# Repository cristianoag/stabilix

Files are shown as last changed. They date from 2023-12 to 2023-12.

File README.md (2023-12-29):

# Stabilix

Stabilix is a spin-off of the self-balancing robot project called B-ROBOT EVO created by JJ Robotics. 

It is a platform for experiments with different sensors and algorithms. The robot is able to balance itself on two wheels and move around avoiding obstacles. The robot is based on ESP32 and it is remotely controlled using a smartphone via Bluetooth.

## Hardware

The robot is based on ESP32 microcontroller and it is remotely controlled using a smartphone via Bluetooth. The robot is equipped with the following hardware components:

* 1 x MPU6050 - 6-axis accelerometer and gyroscope
* 2 x NEMA17 stepper motors
* 2 x A4988 stepper motor drivers
* 1 x ESP32 microcontroller

The robot is powered by a 7.4V LIPO battery pack. The battery is connected to a voltage regulator that converts the voltage to 5V. The 5V is used to power the ESP32 microcontroller and the stepper motor drivers. The stepper motors are powered directly from the battery.

## Assembly

The robot is assembled using 3D printed parts. The 3D models are available in the `3D_models` folder. The robot is assembled using the following parts:

### Bill of materials

| Part name | Quantity | Link |
| --- | --- | --- |
| 3D printed parts | 1 | [Thingiverse](https://www.thingiverse.com/thing:2786294) |

## Software

The robot is programmed in C++ using Arduino IDE. The code is based on the B-ROBOT EVO project created by JJ Robotics. 

## Installation

1. Download and install Arduino IDE from [here](https://www.arduino.cc/en/software)
2. Download and install ESP32 board support for Arduino IDE from [here]()
3. Download the code from this repository and open it in Arduino IDE
4. Connect the robot to your computer using a USB cable
5. Select the correct board and port in Arduino IDE
6. Upload the code to the robot

## Usage

1. Download and install the B-ROBOT EVO app from [here](https://play.google.com/store/apps/details?id=com.jjrobots.brobotevoremotecontrol&hl=en&gl=US)

2. Turn on the robot and connect to it using the app

3. Use the app to control the robot

## Contributing

Pull requests are welcome. For major changes, please open an issue first to discuss what you would like to change.

## License

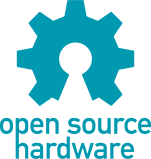
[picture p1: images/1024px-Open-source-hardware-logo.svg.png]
open hardware


This work is licensed under the CERN OHL-S v2. You may redistribute and modify this project and its documentation under the terms of the CERN-OHL-S v2.

This project is distributed WITHOUT ANY EXPRESS OR IMPLIED WARRANTY, INCLUDING OF MERCHANTABILITY, SATISFACTORY QUALITY AND FITNESS FOR A PARTICULAR PURPOSE. Please see the CERN-OHL-S v2 for applicable conditions.

You should have received a copy of the CERN-OHL-S along with this project. If not, see <https://ohwr.org/project/cernohl/wikis/Documents/CERN-OHL-version-2>.

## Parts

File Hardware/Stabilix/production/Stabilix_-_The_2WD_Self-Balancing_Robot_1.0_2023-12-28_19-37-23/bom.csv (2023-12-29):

Designator | Footprint | Quantity | Value | LCSC Part #
BZ1 | Buzzer_12x9.5RM7.6 | 1 | Buzzer
C1, C3 | CP_Radial_D6.3mm_P2.50mm | 2 | 220uF/16V
C2 | CP_Radial_D5.0mm_P2.50mm | 1 | 100uF/16V
D1, D2 | LED_D3.0mm | 2 | LED
J1 | PinHeader_1x04_P2.54mm_Vertical | 1 | NEMA17-M1
J2 | PinHeader_1x04_P2.54mm_Vertical | 1 | NEMA17-M2
J3 | TerminalBlock_bornier-2_P5.08mm | 1 | KF35-2P Battery
J4 | PinHeader_1x02_P2.54mm_Vertical | 1 | Power Switch
J5 | PinHeader_1x03_P2.54mm_Vertical | 1 | Servo
J6 | PinHeader_2x04_P2.54mm_Vertical | 1 | Expansion
R1 | R_Axial_DIN0207_L6.3mm_D2.5mm_P10.16mm_Horizontal | 1 | 1K
U1, U2 | SOT-223-3_TabPin2 | 2 | AMS1117-5.0
U3, U4 | MODULE_A4988_STEPPER_MOTOR_DRIVER_CARRIER | 2 | A4988_STEPPER_MOTOR_DRIVER_CARRIER
U5 | module_mpu6050 | 1 | module_mpu6050
U6 | MODULE_ESP32_DEVKIT_V1 | 1 | ESP32-DEVKIT-V1

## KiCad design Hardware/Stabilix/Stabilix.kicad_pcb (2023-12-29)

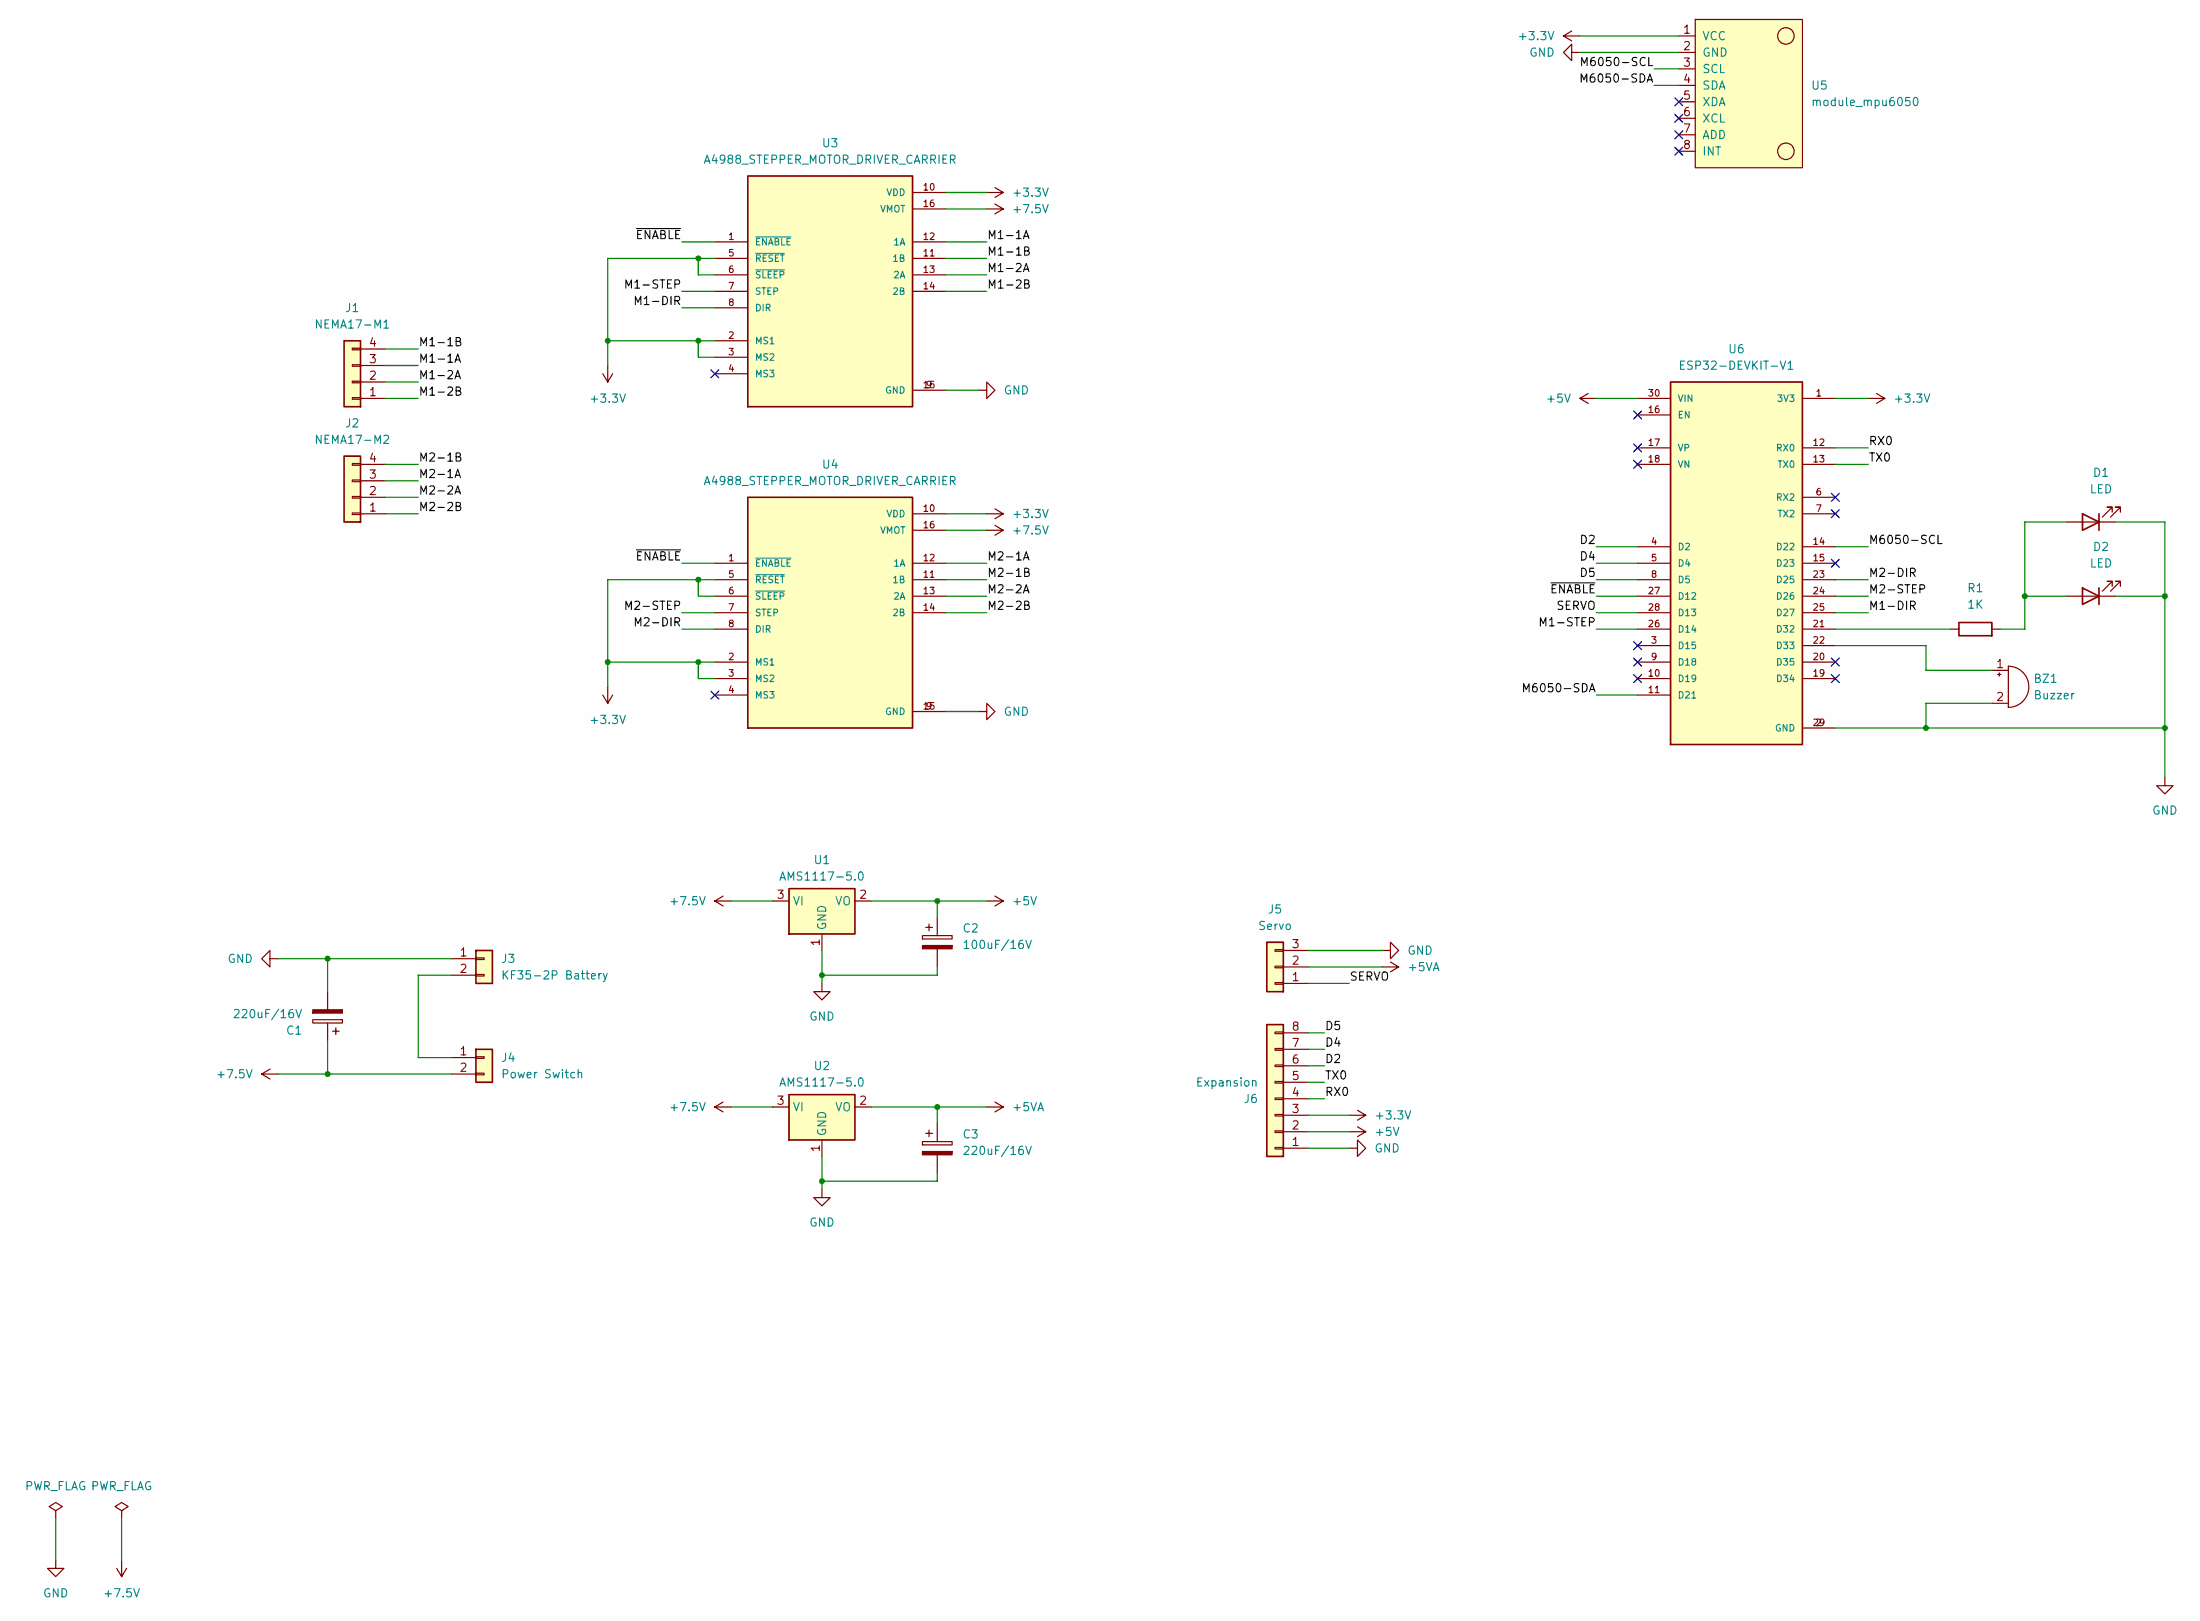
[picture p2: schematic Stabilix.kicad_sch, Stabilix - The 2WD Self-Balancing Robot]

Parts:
BZ1: Buzzer; Buzzer_12x9.5RM7.6
C1, C3: 220uF/16V; CP_Radial_D6.3mm_P2.50mm
C2: 100uF/16V; CP_Radial_D5.0mm_P2.50mm
D1, D2: LED; LED_D3.0mm
J1: NEMA17-M1; PinHeader_1x04_P2.54mm_Vertical
J2: NEMA17-M2; PinHeader_1x04_P2.54mm_Vertical
J3: KF35-2P Battery; TerminalBlock_bornier-2_P5.08mm
J4: Power Switch; PinHeader_1x02_P2.54mm_Vertical
J5: Servo; PinHeader_1x03_P2.54mm_Vertical
J6: Expansion; PinHeader_2x04_P2.54mm_Vertical
R1: 1K; R_Axial_DIN0207_L6.3mm_D2.5mm_P10.16mm_Horizontal
U1, U2: AMS1117-5.0; SOT-223-3_TabPin2
U3, U4: A4988_STEPPER_MOTOR_DRIVER_CARRIER; MODULE_A4988_STEPPER_MOTOR_DRIVER_CARRIER
U5: module_mpu6050
U6: ESP32-DEVKIT-V1; MODULE_ESP32_DEVKIT_V1; PARTREV N/A

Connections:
+3.3V: J6.3, U3.2 (MS1), U3.3 (MS2), U3.5 (~RESET), U3.6 (~SLEEP), U3.10 (VDD), U4.2 (MS1), U4.3 (MS2), U4.5 (~RESET), U4.6 (~SLEEP), U4.10 (VDD), U5.1 (VCC), U6.1 (3V3)
+5V: C2.1, J6.2, U1.2 (VO), U6.30 (VIN)
+5VA: C3.1, J5.2, U2.2 (VO)
+7.5V: C1.1, J4.2, U1.3 (VI), U2.3 (VI), U3.16 (VMOT), U4.16 (VMOT)
/D2: J6.6, U6.4 (D2)
/D4: J6.7, U6.5 (D4)
/D5: J6.8, U6.8 (D5)
/M1-1A: J1.3, U3.12 (1A)
/M1-1B: J1.4, U3.11 (1B)
/M1-2A: J1.2, U3.13 (2A)
/M1-2B: J1.1, U3.14 (2B)
/M1-DIR: U3.8 (DIR), U6.25 (D27)
/M1-STEP: U3.7 (STEP), U6.26 (D14)
/M2-1A: J2.3, U4.12 (1A)
/M2-1B: J2.4, U4.11 (1B)
/M2-2A: J2.2, U4.13 (2A)
/M2-2B: J2.1, U4.14 (2B)
/M2-DIR: U4.8 (DIR), U6.23 (D25)
/M2-STEP: U4.7 (STEP), U6.24 (D26)
/M6050-SCL: U5.3 (SCL), U6.14 (D22)
/M6050-SDA: U5.4 (SDA), U6.11 (D21)
/RX0: J6.4, U6.12 (RX0)
/SERVO: J5.1, U6.28 (D13)
/TX0: J6.5, U6.13 (TX0)
/~ENABLE: U3.1 (~ENABLE), U4.1 (~ENABLE), U6.27 (D12)
GND: BZ1.2 (+), C1.2, C2.2, C3.2, D1.1 (K), D2.1 (K), J3.1, J5.3, J6.1, U1.1 (GND), U2.1 (GND), U3.9 (GND), U3.15 (GND), U4.9 (GND), U4.15 (GND), U5.2 (GND), U6.2 (GND), U6.29 (GND)
unnamed: BZ1.1 (-), U6.22 (D33)
unnamed: D1.2 (A), D2.2 (A), R1.2
unnamed: J3.2, J4.1
unnamed: R1.1, U6.21 (D32)

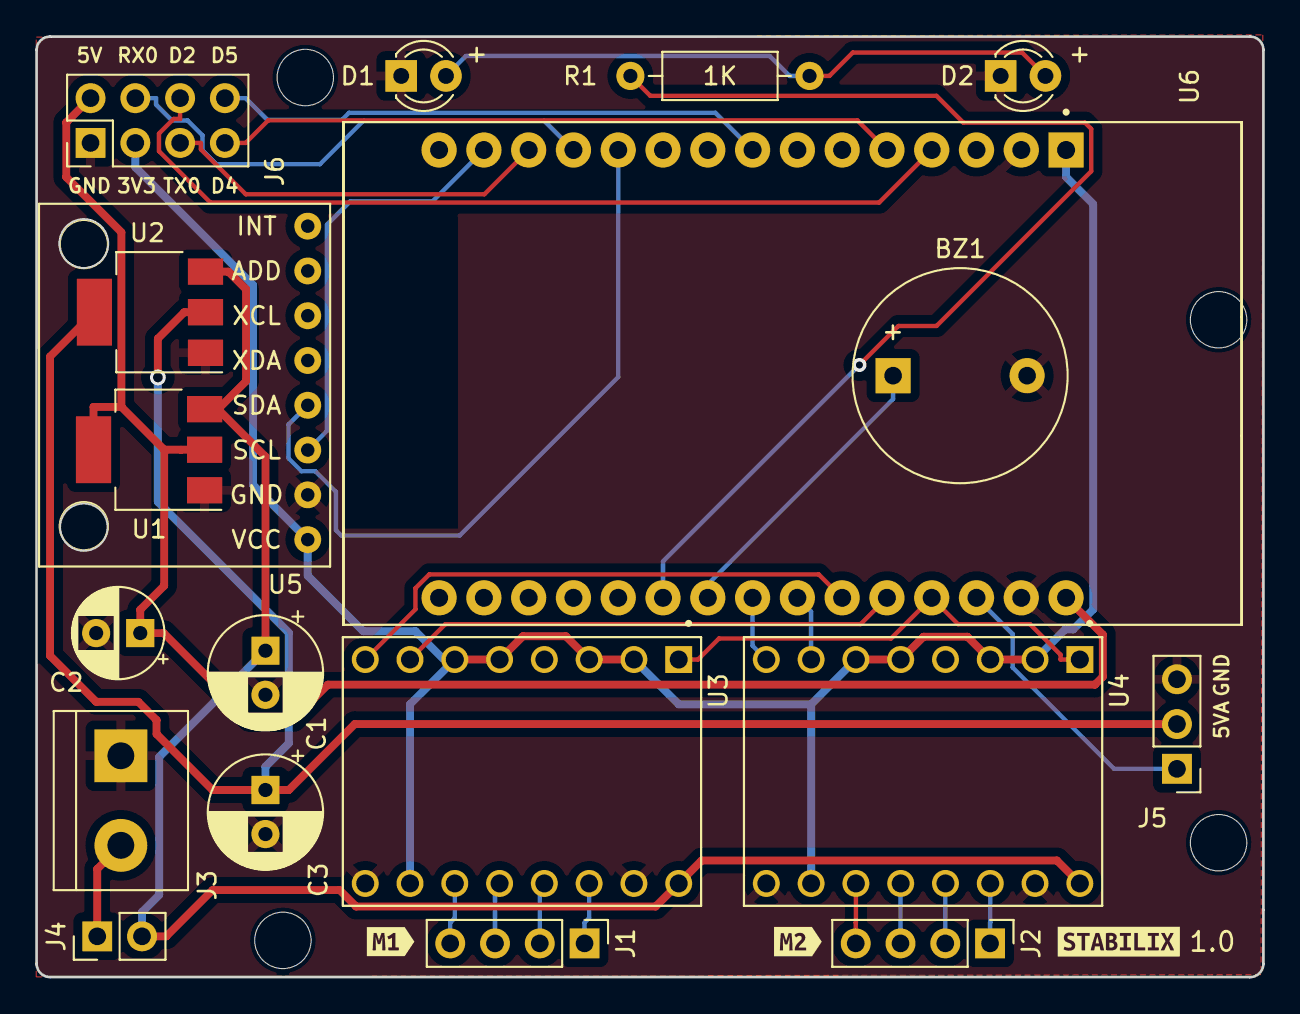
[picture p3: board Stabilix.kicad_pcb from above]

Board: 2 copper layers, 69.6 x 53.3 mm, 26 parts (0 on the bottom side), 30 nets.

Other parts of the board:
MH1, MH2, MH4, MH4#2: MountingHole_3.2mm
kibuzzard-6589FCE6: G***; kibuzzard-6589FCE6
kibuzzard-6589FE3E: G***; kibuzzard-6589FE3E
kibuzzard-6589FE5A: G***; kibuzzard-6589FE5A

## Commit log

2023-12-25 Initial load
    [Stabilix.kicad_pcb, Stabilix.kicad_sch]
2023-12-25 Footprint adjustments
    [Stabilix.kicad_pcb]
2023-12-29 fixes on the screw holes
    [Stabilix.kicad_pcb, bom.csv, designators.csv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]
